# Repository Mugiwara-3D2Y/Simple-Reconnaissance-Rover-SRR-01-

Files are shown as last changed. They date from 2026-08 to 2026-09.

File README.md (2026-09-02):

# Simple-Reconnaissance-Rover-SRR-01-(3D-Model)

> **A project built for Hack Club.**
> *A flexible 4-wheel rover template built for exploration, monitoring, and field testing. Includes ready-to-print 3D models and editable CAD files so you can easily customize it for your own build.*
> **NOTE:** the only use of AI was for describing my project to create this README, about 25%

## Project Deliverables
*  **Onshape Document Link:** https://cad.onshape.com/documents/328f3c9bf33f08104aae075f/w/b1dc5a9cc62e4fa71f2e4275/e/ef0978b53d92c064744758d2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
*  **Print Ready Files:** Located at [/.stl files](./.stl%20files) and [/.step files](./.step%20files).

## Gallery
| Front View | Top View |
| :---: | :---: |
| SRR-01 Front View | SRR-01 Top View |
| **Side View** | **Back View** |
| SRR-01 Side View | SRR-01 Back View |

## Concept
This project is a flexible, modular base designed for building exploration and tracking rovers. Think of the chassis as an adaptable template, it’s built so you can easily mount whatever sensors your project requires, whether you're navigating open fields, detecting life forms, or tracking environmental stats like air quality and humidity. The interior layout is also completely open-ended, giving you plenty of room to set it up for either full autonomy or standard manual remote control.

## Motivation
Designing and building rovers is something I’ve done for a while now. After making several of them, I wanted to create a universal blueprint that saves time and is easy for anyone to build. The idea here is to give makers a reliable foundation that they can easily tweak, allowing them to specialize the rover for real-world applications like smart agriculture, environmental exploration, or recovery efforts.

## Tech Stack
*  **CAD Software:** Onshape
*  **Design Paradigm:** Parametric modeling
*  **Target Manufacturing Process:** FDM 3D Printing

## Features
* I designed this rover to be tough enough for the field but simple enough for anyone to actually build:
1. **Articulated Suspension Legs:**
   * To give the rover its wide stance and high ground clearance, the suspension arms utilize 3/4-inch PVC pipes as the structural bone template. The CAD-printed leg joints are designed to slide onto these pipes at a fixed angle, allowing the rover to climb over rocks, agricultural ridges, or debris without high-centering the main body.
2. **M3 Screw Fastener:**
   * Every single shell, joints, and mounting bracket is secured using standard M3 screws. By designing the entire chassis around a single fastener size, it simplifies assembly, keeps weight down, and ensures that anyone building this can easily source or swap out parts without needing a massive tool kit.
3. **Modular Sensor Mounts:**
   * The main body features built-in mounting points ready for hardware customizability. The top lid includes pre-modeled slots that can take various environmental sensors(like DHT22 or MQ135), while the angled front nose features a dedicated bracket for a camera and dual-port cutouts in-front and at the back for two ultrasonic sensors.
4. **Rugged Outboard Wheels & Fenders:**
   * The wheels are pushed far out to the corners of the frame to give the rover maximum stability on steep slopes. Each wheel includes an integrated fender to keep dirt and debris from kicking up into the moving joints during outdoor testing.
5. **Enclosed Electronics:**
   * The main body features a spacious, multi-faceted top lid labeled SRR-01. This protective shell fully encloses the internal compartment, keeping sensitive microcontrollers, motor drivers, and battery packs safe from dust, debris, or moisture during field operations.

## Production Settings
Since this project is designed as a template, the final slicing settings will ultimately depend on what material you choose and how tough you need your rover to be. That said, here are the recommended base settings I’ve used for printing a durable, field-ready build:

| Slicing Parameter | Recommended Setting |
| :--- | :--- |
| Material | PETG |
| Layer Height | 0.16 mm |
| Infill density | 20% |
| Infill Pattern | Gyroid |
| Perimeters | 4 |
| Top/Bottom Layers | 4 Top / 4 Bottom |
| Supports | Tree |

> **Tolerance Note:** The M3 screw holes and PVC pipe sockets in the CAD model are designed with standard clearance tolerances. If your printer tends to over-extrude slightly, set your slicer's **XY Size Compensation** to `-0.05 mm` or `-0.1 mm` so the PVC pipes slide snugly into the leg joints without needing forced reaming.

> Turn off "Don't create support under brigdes" for [Front Cover Chasis](./.stl%20files/Chasis/Chasis%20-%20Front%20Cover.stl) and [Back Cover Chasis](./.stl%20files/Chasis/Chasis%20-%20Back%20Cover.stl).

## Bill of Materials (BOM)

If you want to skip the CAD tweaking and jump straight into printing and assembling a fully functional rover, here is everything you need to build the base model (`SRR-01`):

### Hardware & Fasteners
* **3/4-inch PVC Pipe:** 2x 90mm and 6x 60mm (or cut to your desired length for the leg joints).
* **M3 Screw Pack:** 
  * M3 × 8mm, 12mm and 40mm Screws 
  * M3 Hex Nuts 
* **Wheels:** 4x 65mm Robot Smart Car Wheels (Hex hub compatible for couplers)
* **Couplers:** 4x 18mm Hex couplings

### Recommended Core Electronics
* **Microcontroller** ESP32 or Arduino Uno
* **Motors:** 4x JGA25-370
* **Motor Drivers:** 2x L298N
* **Power Source:** 2S/3S LiPo battery pack or a 6×AA battery holder
* **GPS:** Ublox Neo GPS Module

### Sensors
* **Camera:** Logitech c270 web cam (or any other camera)
* **2x HC-SR04 Ultrasonic Sensors** 
* **DHT11 / DHT22 Temperature & Humidity sensor**
* **MQ-135 Gas sensor**

## Printing Process

Below outlines the time it takes to print each part based on the Production Settings.

| Part | Time |
| :--- | :--- |
| [Front Base Chasis](./.stl%20files/Chasis/Chasis%20-%20Front%20Base.stl) | **6 hours** |
| [Back Base Chasis](./.stl%20files/Chasis/Chasis%20-%20Back%20Base.stl) | **7 hours** |
| [Front Cover Chasis](./.stl%20files/Chasis/Chasis%20-%20Front%20Cover.stl) | **9 hours 30 minutes** |
| [Back Cover Chasis](./.stl%20files/Chasis/Chasis%20-%20Back%20Cover.stl) | **11 hours 30 minutes** |
| [Left Hand Chasis](./.stl%20files/Chasis/Chasis%20-%20Left%20Hand.stl) | **2 hours 20 minutes** |
| [Right Hand Chasis](./.stl%20files/Chasis/Chasis%20-%20Right%20Hand.stl) | **2 hours 20 minutes** |
| [Right Front PVC Pipe Joint](./.stl%20files/PVC%20Pipe%20Joint/PVC%20Pipe%20Joint%20-%20(Right%20Front%20or%20Left%20Rear).stl) | **1 hours 40 minutes** |
| [Right Rear PVC Pipe Joint](./.stl%20files/PVC%20Pipe%20Joint/PVC%20Pipe%20Joint%20-%20(Right%20Rear%20or%20Left%20Front).stl) | **1 hours 40 minutes** |
| [Left Rear PVC Pipe Joint](./.stl%20files/PVC%20Pipe%20Joint/PVC%20Pipe%20Joint%20-%20(Right%20Front%20or%20Left%20Rear).stl) | **1 hours 40 minutes** |
| [Left Front PVC Pipe Joint](./.stl%20files/PVC%20Pipe%20Joint/PVC%20Pipe%20Joint%20-%20(Right%20Rear%20or%20Left%20Front).stl) | **1 hours 40 minutes** |
| [Left Front Wheel Mount](./.stl%20files/Wheel%20Mount/Wheel%20Mount%20-%20Left%20Front.stl) | **3 hours 30 minutes** |
| [Left Rear Wheel Mount](./.stl%20files/Wheel%20Mount/Wheel%20Mount%20-%20Left%20Rear.stl) | **3 hours 20 minutes** |
| [Right Front Wheel Mount](./.stl%20files/Wheel%20Mount/Wheel%20Mount%20-%20Right%20Front.stl) | **3 hours 30 minutes** |
| [Right Rear Wheel Mount](./.stl%20files/Wheel%20Mount/Wheel%20Mount%20-%20Rigth%20Rear.stl) | **3 hours 20 minutes** |
| **Total** | **59 hours** |

## Assembly Guide

Assembling the base `SRR-01` takes about 30–45 minutes once all your parts are printed. Here is how it goes together:

### Step 1: eLower Chasis
* **Get the [Front Base](./.stl%20files/Chasis/Chasis%20-%20Front%20Base.stl) and [Back Base](./.stl%20files/Chasis/Chasis%20-%20Back%20Base.stl) of the chasis and insert an HC-SR04 ultrasonic sensor in each part.**
<table>
  <tr>
    <td align="center">
      STEP 1
    </td>
    <td align="center">
      STEP 3
    </td>
  </tr>
  <tr>
    <td align="center">
      STEP 2
    </td>
    <td align="center">
      STEP 4
    </td>
  </tr>
</table>

* **Join the two bases together then fasten them with 3 m3*8mm Screws and nuts**
<table>
  <tr>
    <td align="center">
      STEP 6
    </td>
    <td align="center">
      STEP 7
    </td>
  </tr>
</table>

* **Add the [Left Hand](./.stl%20files/Chasis/Chasis%20-%20Left%20hand.stl) and [Right Hand](./.stl%20files/Chasis/Chasis%20-%20Right%20hand.stl) to the base respectively. After that fasten them with 8 m3*8mm Screws and nuts**
<table>
  <tr>
    <td align="center">
      STEP 9
    </td>
    <td align="center">
      STEP 10
    </td>
  </tr>
</table>

### Step 2: Rover Legs
* **Slide a JGA25-370 motor into the [Left Front Wheel Mount](./.stl%20files/Wheel%20Mount/Wheel%20Mount%20-%20Left%20Front.stl) with two m3*12mm Screws.**
<table>
  <tr>
    <td align="center">
      STEP 11
    </td>
    <td>
      STEP 12
    </td>
    <td>
      STEP 13
    </td>
  </tr>
</table>

* **Next fix one 30mm PVC Pipe in the [Left Front Wheel Mount](./.stl%20files/Wheel%20Mount/Wheel%20Mount%20-%20Left%20Front.stl) followed by the [Left Front PVC Pipe Joint](./.stl%20files/PVC%20Pipe%20Joint/PVC%20Pipe%20Joint%20-%20(Right%20Rear%20or%20Left%20Front).stl) aligned correspondingly.**
<table>
  <tr>
    <td align="center">
      STEP 14
    </td>
    <td align="center">
      STEP 15
    </td>
  </tr>
</table>

* **After that, fit a 60mm Pipe into the [Left Front PVC Pipe Joint](./.stl%20files/PVC%20Pipe%20Joint/PVC%20Pipe%20Joint%20-%20(Right%20Rear%20or%20Left%20Front).stl)**
<table>
  <tr>
    <td align="center">
      STEP 16
    </td>
    <td align="center">
      STEP 17
    </td>
  </tr>
</table>

* **Repeat Steps 2.1, 2.2 and 2.33 with the [Left Rear Wheel Mount](./.stl%20files/Wheel%20Mount/Wheel%20Mount%20-%20Left%20Rear.stl), [Left Rear PVC Pipe Joint](./.stl%20files/PVC%20Pipe%20Joint/PVC%20Pipe%20Joint%20-%20(Right%20Front%20or%20Left%20Rear).stl) and a 30mm PVC Pipe**
<table>
  <tr>
    <td align="center">
      STEP 18
    </td>
    <td align="center">
      STEP 19
    </td>
  </tr>
  <tr>
    <td align="center'>
      STEP 20
    </td>
    <td align="center">
     STEP 21
    </td>
  </tr>
  <tr>
    <td align="center">
      STEP 22
    </td>
    <td align="center">
      STEP 23
    </td>
  </tr>
</table>

* **Gather the two separate assemblies and add them to the Bottom Chasis from Step 1.**
<table>
  <tr>
    <td align="center">
      STEP 24
    </td>
    <td align="center">
      STEP 25
    </td>
  </tr>
</table>

* **Repeat the whole of Step 2 so far with [Right Front Wheel Mount](./.stl%20files/Wheel%20Mount/Wheel%20Mount%20-%20Right%20Front.stl), [Right Rear Wheel Mount](./.stl%20files/Wheel%20Mount/Wheel%20Mount%20-%20Rigth%20Rear.stl), [Right Front PVC Pipe Joint](./.stl%20files/PVC%20Pipe%20Joint/PVC%20Pipe%20Joint%20-%20(Right%20Front%20or%20Left%20Rear).stl) and [Right Rear PVC Pipe Joint](./.stl%20files/PVC%20Pipe%20Joint/PVC%20Pipe%20Joint%20-%20(Right%20Rear%20or%20Left%20Front).stl).**
<table>
  <tr>
    <td align="center">
      STEP 26
    </td>
    <td align="center">
      STEP 27
    </td>
  </tr>
</table>

### Step 3: Upper Chasis
* **Attach a DHT22 Temperature & Humidity sensor, an Ublox Neo GPS and a MQ-135 Gas sensor to the [Back Cover Chasis](./.stl%20files/Chasis/Chasis%20-%20Back%20Cover.stl). Use 4 m3*5mm Screws to fasten the Gas sensor.
<table>
  <tr>
    <td align="center">
      STEP 29
    </td>
    <td align="center">
      STEP 30
    </td>
    <td align="center">
      STEP 31
    </td>
  </tr>
</table>

* **Now fasten the [Back Cover Chasis](./.stl%20files/Chasis/Chasis%20-%20Back%20Cover.stl) to the Bottom Chasis with 2 m3*40mm**
<table>
  <tr>
    <td align="center">
      STEP 32
    </td>
    <td align="center">
      STEP 33
    </td>
  </tr>
</table>

* **Take the [Front Cover Chasis](./.stl%20files/Chasis/Chasis%20-%20Front%20Cover.stl) and attach a camera to the space infront.**
<table>
  <tr>
    <td align="center">
      STEP 34
    </td>
    <td align="center">
      STEP 35
    </td>
  </tr>
</table>

* **Fix the [Front Cover Chasis](./.stl%20files/Chasis/Chasis%20-%20Front%20Cover.stl) to the Bottom Chasis with 2 m3*40mm and 2 m3*8mm**
<table>
  <tr>
    <td align="center">
      STEP 36
    </td>
    <td align="center">
      STEP 37
    </td>
  </tr>
</table>

>  Working on it...

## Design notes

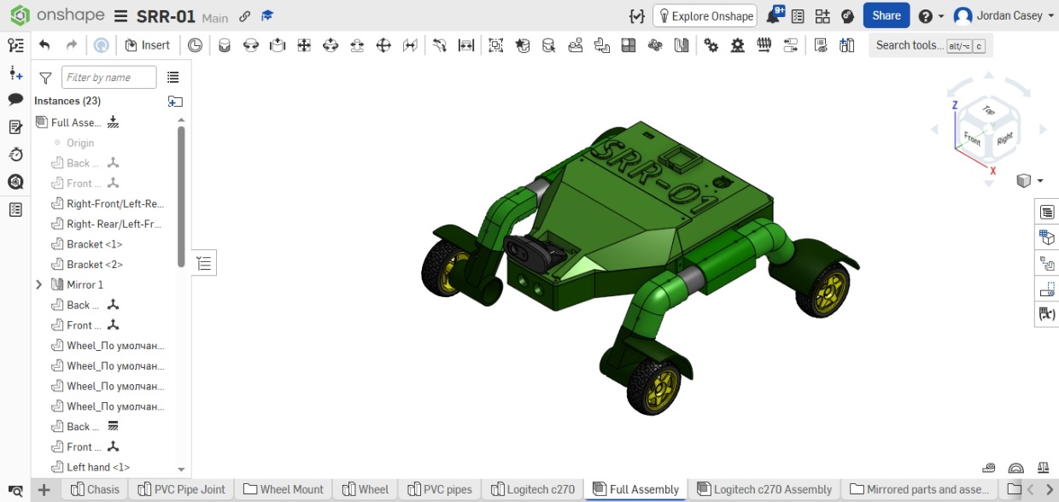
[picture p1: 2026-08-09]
SRR-01 Isometric Image.jpeg

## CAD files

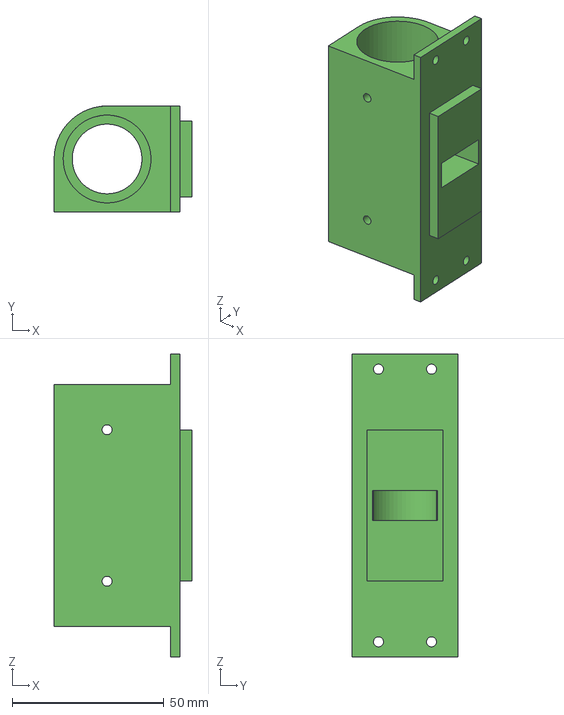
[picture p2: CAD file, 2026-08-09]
.step files/Chasis/Chasis - Right Hand.step
45.5 x 35.0 x 100.0 mm

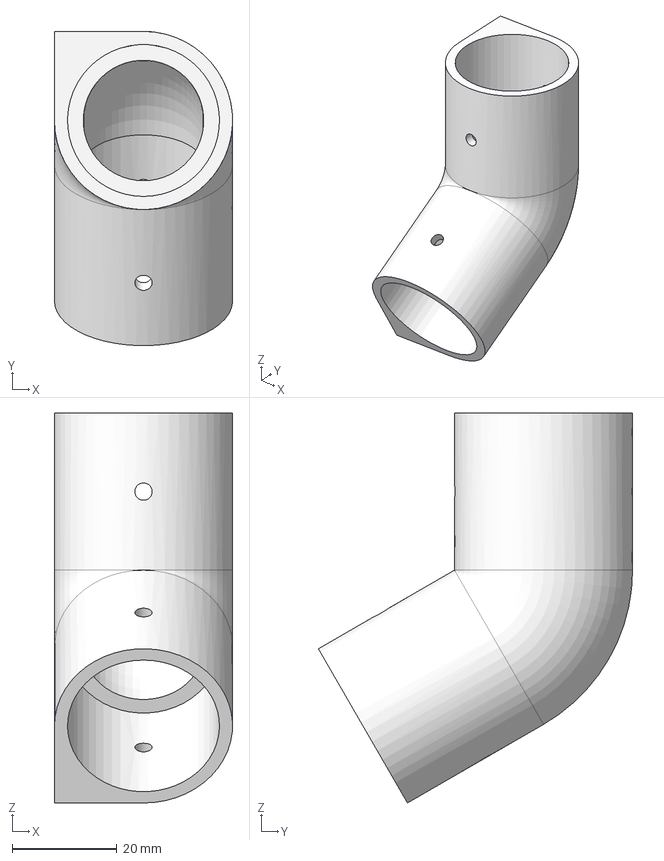
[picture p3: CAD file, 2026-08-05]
.step files/PVC Pipe Joint/PVC Pipe Joint - (Right Front or Left Rear).step
34.0 x 60.0 x 74.4 mm

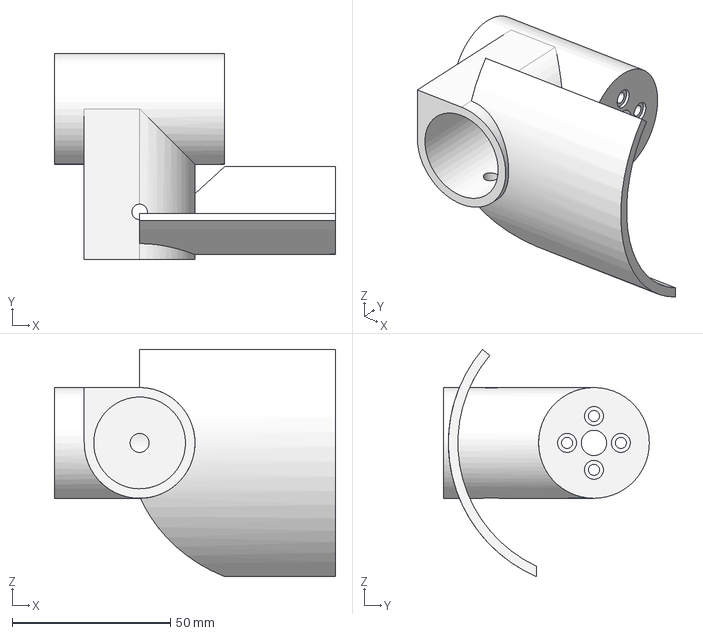
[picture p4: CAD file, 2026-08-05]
.step files/Wheel Mount/Wheel Mount - Right Rear.step
88.8 x 65.0 x 71.8 mm

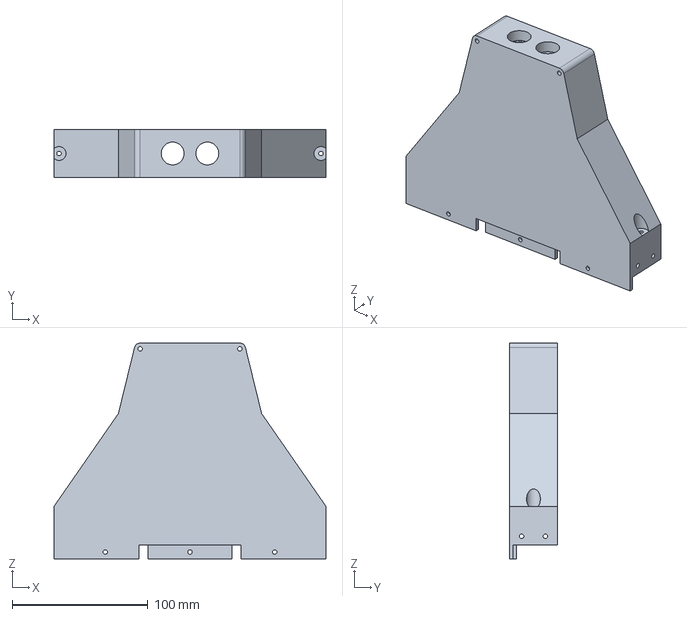
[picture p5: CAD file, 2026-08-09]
.step files/Chasis/Chasis - Front Base.step
200.0 x 35.0 x 158.6 mm

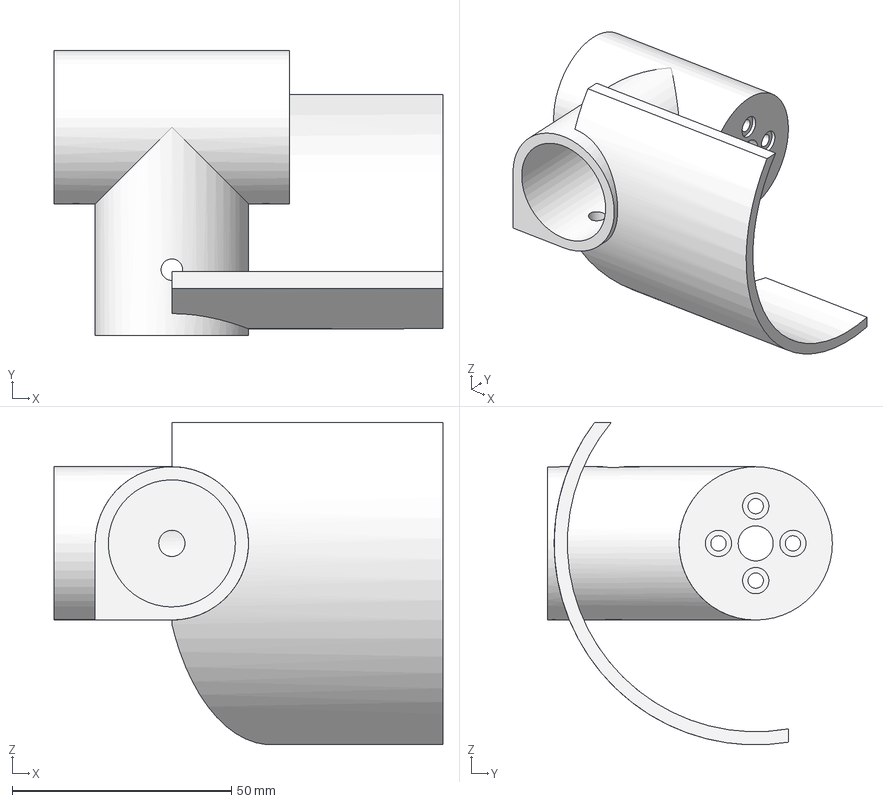
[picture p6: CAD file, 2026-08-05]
.step files/Wheel Mount/Wheel Mount - Right Front.step
88.8 x 65.0 x 73.6 mm

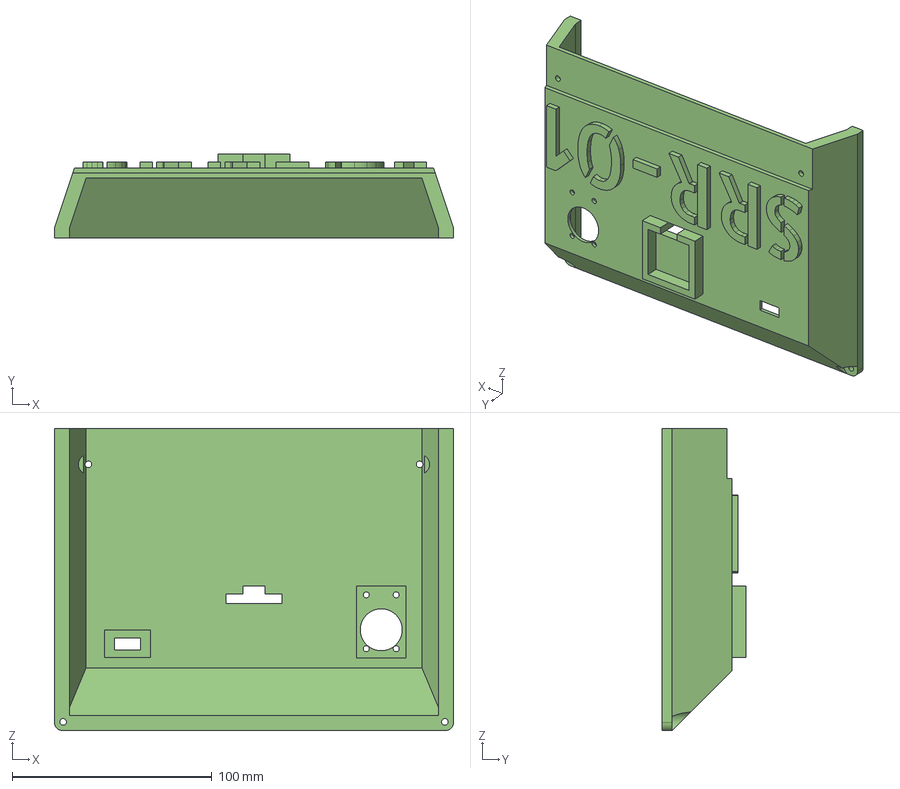
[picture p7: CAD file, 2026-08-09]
.step files/Chasis/Chasis - Back Cover.step
200.0 x 42.0 x 151.4 mm

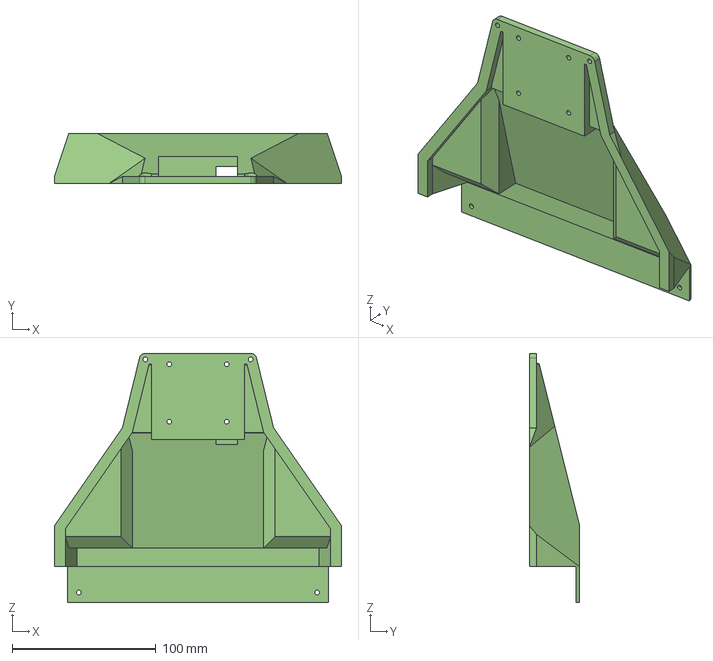
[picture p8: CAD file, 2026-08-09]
.step files/Chasis/Chasis - Front Cover.step
200.0 x 35.0 x 173.6 mm

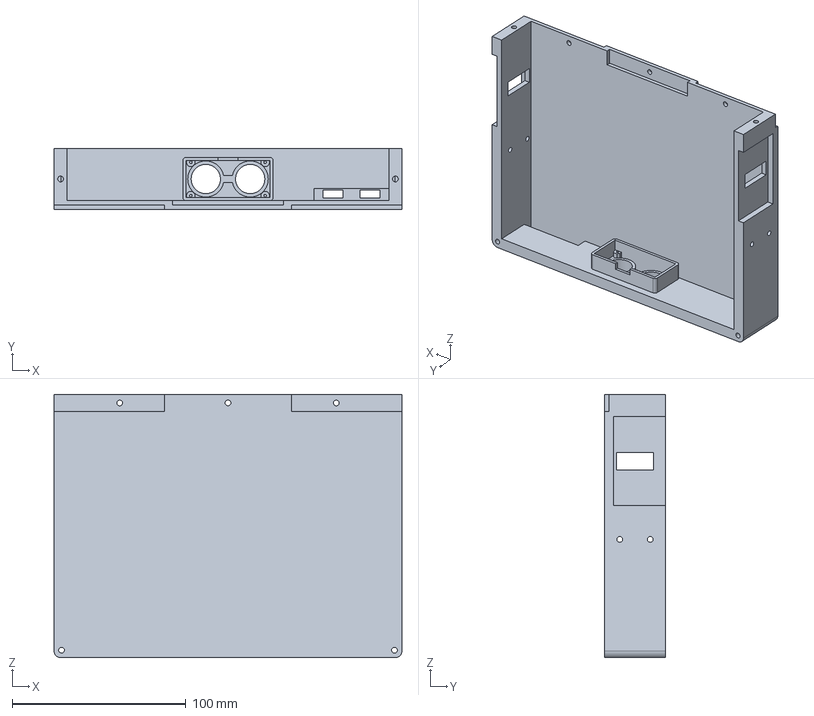
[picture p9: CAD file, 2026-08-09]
.step files/Chasis/Chasis - Back Base.step
200.0 x 35.0 x 151.4 mm

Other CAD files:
.step files/Chasis/Chasis - Left Hand.step
.step files/PVC Pipe Joint/PVC Pipe Joint - (Right Rear or Left Front).step
.step files/Wheel Mount/Wheel Mount - Left Rear.step
.step files/Wheel Mount/Wheel Mount - Left Front.step
.stl files/Chasis/Chasis - Back Base.stl
.stl files/Chasis/Chasis - Back Cover.stl
.stl files/Chasis/Chasis - Front Base.stl
.stl files/Chasis/Chasis - Front Cover.stl
.stl files/Chasis/Chasis - Left Hand.stl
.stl files/Chasis/Chasis - Right Hand.stl
.stl files/PVC Pipe Joint/PVC Pipe Joint - (Right Front or Left Rear).stl
.stl files/PVC Pipe Joint/PVC Pipe Joint - (Right Rear or Left Front).stl
.stl files/Wheel Mount/Wheel Mount - Left Front.stl
.stl files/Wheel Mount/Wheel Mount - Left Rear.stl
.stl files/Wheel Mount/Wheel Mount - Right Front.stl
.stl files/Wheel Mount/Wheel Mount - Right Rear.stl

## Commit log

2026-08-03 PVC Pipe Joint
    [PVC Pipe Joint - (Right Front or Left Rear).stl, PVC Pipe Joint - (Right Rear or Left Front).stl]
2026-08-03 wheels mount
    [Wheel Mount - Left Front.stl, Wheel Mount - Left Rear.stl, Wheel Mount - Right Front.stl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]
2026-08-05 Moved folders into new parent folder
    [PVC Pipe Joint - (Right Front or Left Rear).stl, PVC Pipe Joint - (Right Rear or Left Front).stl, Wheel Mount - Left Front.stl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]
2026-08-05 New files
    [PVC Pipe Joint - (Right Front or Left Rear).step, PVC Pipe Joint - (Right Rear or Left Front).step, Wheel Mount - Left Front.step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]
2026-08-09 Added new folder
    [Chasis - Back Base.stl, Chasis - Back Cover.stl, Chasis - Front Base.stl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]
2026-08-09 Added a new folder
    [Chasis - Back Base.step, Chasis - Back Cover.step, Chasis - Front Base.step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]
2026-08-14 Renamed folder
    [Chasis - Back Base.step, Chasis - Back Cover.step, Chasis - Front Base.step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]
2026-08-17 Renamed Incorrectly Named Files
    [Wheel Mount - Left Front.step, Wheel Mount - Left Front.stl, Wheel Mount - Left Rear.step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]
2026-08-31 Renamed Files
    [Chasis - Left Hand.step, Chasis - Left Hand.stl, Chasis - Right Hand.step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]
